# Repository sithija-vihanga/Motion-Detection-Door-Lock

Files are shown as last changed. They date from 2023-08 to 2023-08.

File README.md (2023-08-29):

# Access Smart: Smart Door Lock with Motion Detection

Access Smart is a revolutionary smart door lock that combines motion detection technology and a 4-digit PIN entry system for enhanced security and convenience. This project report provides insights into its specifications, features, assembly instructions, and testing methodologies.

<div align="center">
  <a href="https://github.com/sithija-vihanga/Motion-Detection-Door-Lock/assets/116638289/a954cdd1-04aa-4a93-a124-b1647b821518">
    
  </a>
  <a href="https://github.com/sithija-vihanga/Motion-Detection-Door-Lock/assets/116638289/baeaff62-b7b3-4b20-9fbe-9ba9ac5b796d">
    
  </a>
</div>

## Abstract

Access Smart is a groundbreaking smart door lock that redefines access control for both homes and businesses. This innovative security solution seamlessly integrates motion detection technology and a 4-digit PIN entry system, providing robust security and convenience. With continuous AC power and a reliable Li-ion battery backup, Access Smart operates flawlessly in any situation. The standout feature is its GSM SIM 900A module, allowing real-time SMS alerts for suspicious activities near the door. This report covers specifications, Bill of Materials (BoM), schematics, SolidWorks designs, and more, making Access Smart the ideal solution for modern access control needs.

## Features

- Continuous Power Supply: Utilizes a 12V, 2A power adaptor for uninterrupted operation.
- Backup Power: Employs a TP4056 Li-ion battery charger for backup power.
- Overcharging and Short Circuit Protection: TP4056 module ensures safe charging.
- Buzzer for Notifications: Provides audible alerts for PIN entry or motion detection.
- Manual and Automatic Modes: Secure PIN entry or automatic unlocking via motion detection.
- Easy Manual Unlocking: Pushbutton located inside the house for manual unlocking.
- Intruder Alert: Sends SMS alerts for suspicious activity using PIR sensor and GSM module.

## Specifications

- Microcontroller: Atmega 328p
- Power Supply: 12V, 2A AC Power Adaptor
- Backup Power: 3.7V 18650 Li-ion Battery
- Battery Charger: TP4056 Module with Overcharging and Short Circuit Protection
- User Input: 4x4 Keypad (4-Digit PIN Entry), PIR Sensor (Motion Detection)
- Output: Buzzer, MG90 Metal Servo for Locking Mechanism
- Communication: GSM SIM 900A Module
- Dimensions: 15cm x 12cm

## Installation and Assembly

For detailed assembly instructions and testing procedures, please refer to the [Instructions for Assembly](#instructions-for-assembly) section in the project report PDF.

## Schematics and Designs

<table>
  <tr>
    <td align="center">
      <a href="https://github.com/sithija-vihanga/Motion-Detection-Door-Lock/assets/116638289/c917862b-291f-4ac9-ad59-d2e63189d771">
        Schematics
      </a>
      <br />
      Micro-controller
    </td>
    <td align="center">
      <a href="https://github.com/sithija-vihanga/Motion-Detection-Door-Lock/assets/116638289/85c1b217-390d-44d3-b0bd-173bbbe9d299">
        SolidWorks Design
      </a>
      <br />
      Output-Sensors
    </td>
    <td align="center">
      <a href="https://github.com/sithija-vihanga/Motion-Detection-Door-Lock/assets/116638289/3c5293ef-08f0-4463-aaf7-4a20a470f573">
        
      </a>
      <br />
      Input-Sensors
    </td>
  </tr>
  <tr>
    <td align="center">
      <a href="https://github.com/sithija-vihanga/Motion-Detection-Door-Lock/assets/116638289/dda05f63-1226-4be6-8466-62b0edfdb50d">
        
      </a>
      <br />
      Power-Supply
    </td>
   
  </tr>
 
</table>

## PCB-Design

<div align="center">
  <a href="https://github.com/sithija-vihanga/Motion-Detection-Door-Lock/assets/116638289/617d1b62-6401-47f7-aab8-b14efe2582e4">
    
  </a>
  <a href="https://github.com/sithija-vihanga/Motion-Detection-Door-Lock/assets/116638289/75c37d61-a14a-433e-931d-eac69ed96c83">
    
  </a>
  <a href="https://github.com/sithija-vihanga/Motion-Detection-Door-Lock/assets/116638289/a294f43c-3b7f-41c9-a379-642b3d2e740c">
    
  </a>
</div>

## Solidworks Design

<table>
  <tr>
    <td align="center">
      <a href="https://github.com/sithija-vihanga/Motion-Detection-Door-Lock/assets/116638289/7449ecb6-f5ca-4ba5-8e76-e4704d8df172">
        
      </a>
      <br />
      Image 1
    </td>
    <td align="center">
      <a href="https://github.com/sithija-vihanga/Motion-Detection-Door-Lock/assets/116638289/8038393a-3e27-4574-94a8-9115b9612055">
        
      </a>
      <br />
      Image 2
    </td>
  </tr>
  <tr>
    <td align="center">
      <a href="https://github.com/sithija-vihanga/Motion-Detection-Door-Lock/assets/116638289/9feb5a9c-0473-42e9-8e31-26115e73f358">
        
      </a>
      <br />
      Image 3
    </td>
    <td align="center">
      <a href="https://github.com/sithija-vihanga/Motion-Detection-Door-Lock/assets/116638289/021b66cf-a933-4240-a657-117ee0a4700b">
        
      </a>
      <br />
      Image 4
    </td>
  </tr>
</table>

## Testing and Validation

Refer to the [Testing and validating functionality](#testing-and-validating-functionality) section in the project report PDF for testing procedures.

## License

For more details, please read the complete project report provided in the repository.

---

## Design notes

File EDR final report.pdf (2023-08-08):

### DEPARTMENT OF ELECTRONIC AND TELECOMMUNICATION ENGINEERING UNIVERSITY OF MORATUWA

## EN2160: ELECTRONIC DESIGN REALIZATION

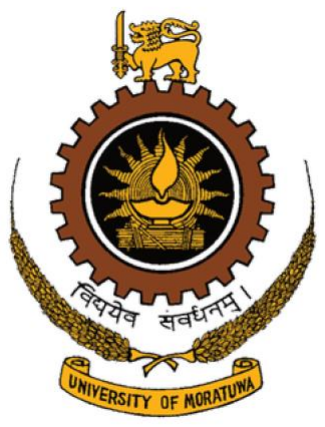
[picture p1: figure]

# Access Smart FINAL PRODUCT REPORT

## Ranaraja S.V

200506K

22

nd July 2023

## Table of Contents

### 1. Introduction

1.1 Overview

### 2. Product Goals

2.1 Functionality
2.2 Market Goals
2.3 Price

### 3. Features

3.1 Uninterrupted power supply
3.2 Charging and discharging protection 3.3 Intruder alerts with SMS

### 4. Specifications

4.1 Motion Detection Technology
4.2 PIN Entry System
4.3 Power Supply: AC Power and Li-ion Battery Backup 4.4 GSM SIM 900A Module for SMS Alerts

### 5. Bill of Materials (BoM)

5.1 Components List and manufacturer

### 6. Schematics and SolidWorks Designs

6.1 Circuit Schematics
6.2 SolidWorks 3D Design
7. Assembly and Testing
7.1 Testing for Power Input and Power LED 7.2 TP4056 Module Charging Test
7.3 Debugging Charging and Discharging Circuit 7.4 ATMEGA and OLED Connection Test
7.5 Motion Sensor Testing
7.6 GSM SIM 900A Module Network Connection Test

## Abstract

Access Smart is a revolutionary smart door lock that redefines door access control for both homes and businesses. This advanced security solution seamlessly integrates motion detection technology and a 4-digit PIN entry system, ensuring enhanced security and convenience. With continuous power supply through AC power and a reliable Li-ion battery backup, Access Smart operates flawlessly in any situation.

The standout feature of Access Smart lies in its incorporation of a GSM SIM 900A module, enabling real-time SMS alerts when suspicious activities are detected near the door. The product report provides comprehensive insights into its specifications, Bill of Materials (BoM), schematics, SolidWorks designs, conceptual design, and preliminary design. Market goals are directed towards homeowners, office spaces, and small businesses seeking an intelligent and modern access control system at a competitive price point. Assembling instructions and testing methodologies are also covered to ensure seamless implementation and optimum functionality. Access Smart, with its cutting-edge technology, convenience, and robust security measures, promises to be the go-to solution for modern door access control needs.

### Smart Door Lock with Motion Detection – Report

### 1. Introduction

Introduction:
The smart door lock with motion detection is designed to provide enhanced security and convenience for door access. It incorporates features intruder alerts using SMS facility to pre-entered phone number, motion detection automatic lock and continuous power supply through AC power and backup power using a Li-ion battery. The lock offers two modes: manual mode with a 4-digit PIN entry and automatic mode utilizing motion detection. This innovative device aims to safeguard premises from potential threats by detecting suspicious activities near the door and sending real-time SMS alerts using the GSM SIM 900A module.

Product Goals:
The primary functionality of the smart door lock is to offer secure and convenient access control to residential and commercial spaces. It combines motion detection and PIN entry to ensure only authorized individuals can enter the premises. The market goals focus on targeting homeowners, office spaces, and small businesses seeking an efficient and modern access control system. The pricing strategy aims to strike a balance between affordability and value, making the smart door lock an attractive choice for consumers seeking advanced security solutions.

Price
Approximate Cost per Unit – Rs. 18,000.00
Market Price – Rs. 20,000.00
Annual Gross Profit – Rs. 200,000.00

### 2. Features

- Continuous Power Supply: Utilizes a 12V, 2A power adaptor to provide uninterrupted power to the smart door lock.
- Backup Power: Employs a TP4056 Li-ion battery charger to charge a 3.7V 18650 battery, offering backup power in case of AC power failure.
- Overcharging and Short Circuit Protection: The TP4056 module ensures safe charging of the Li-ion battery by providing overcharging and short circuit protection.
- Buzzer for Notifications: Incorporates a buzzer to provide audible notifications for various events, such as successful/unsuccessful PIN entry or motion detection.
- Manual Mode: Enables secure access with a 4-digit PIN. The door can be opened by entering the correct PIN.
- Automatic Mode: Utilizes motion detection to automatically unlock the door when motion is detected.
- Easy access for door lock from inside the house: pushbutton is located on the other side of the door lock, allowing for easy manual unlocking from inside.
- Trigger Mechanism: Employs an MG90 metal servo to trigger the locking mechanism securely.
- Intruder alert: Notify users when suspicious activity is detected near the door using PIR sensor readings through SMS facility.

### 3. Specifications

Microcontroller: Atmega 328p
Power Supply: 12V, 2A AC Power Adaptor
Backup Power: 3.7V 18650 Li-ion Battery
Battery Charger: TP4056 Module with Overcharging and Short Circuit Protection User Input: 4x4 keypad (4-Digit PIN Entry), PIR sensor (Motion Detection) Output: Buzzer, MG90 Metal Servo for Locking Mechanism
Communication: GSM sim 900A module
Dimensions: 15cm x 12cm

### 04. Bill of Materials (BoM)

Component | Manufacturer | Shop
Diodes 1N4007 x 10 | Diodes Incorporated | Arrow
Capacitors (electrolytic) | Panasonic | Arrow
1uF x 5 | Panasonic | Arrow
10uF x 5 | Panasonic | Arrow
Capacitors (non-electrolytic) | Vishay | LCSC
22pF x 5 | Vishay | LCSC
Crystal Oscillator 16MHz | Abracon | LCSC
Voltage Regulators | STMicroelectronics | Arrow
L7805CV x 3 | STMicroelectronics | Arrow
L78S05 x 3 | STMicroelectronics | Arrow
SMD Green LED x 5 | Lite-On Technology | Arrow
TP4056 Modules x 2 | | Tronic.lk
12V Power Adaptor | - -
2-pin Power Connectors x 5 | JST | LCSC
3-pin Header Connectors x 5 | JST | LCSC

4-pin Header Connectors x 5 | JST | LCSC
8-pin Connectors x 2 | JST | LCSC
Li-ion Single Battery Case x 2 | Adafruit | LCSC
PIR Motion Sensor x 1 | HC-SR501 | Tronic.lk
Push Button x 1 | Tactile Push Button | Tronic.lk
Buzzer x 1 | Piezo Buzzer | LCSC
1K x 10 | Vishay | LCSC
10K x 10 | Vishay | LCSC
Atmega 328p x 1 | | LCSC
Upconverter (5V - 24V) | - | Tronic.lk
GSM Sim900A module | - | LCSC

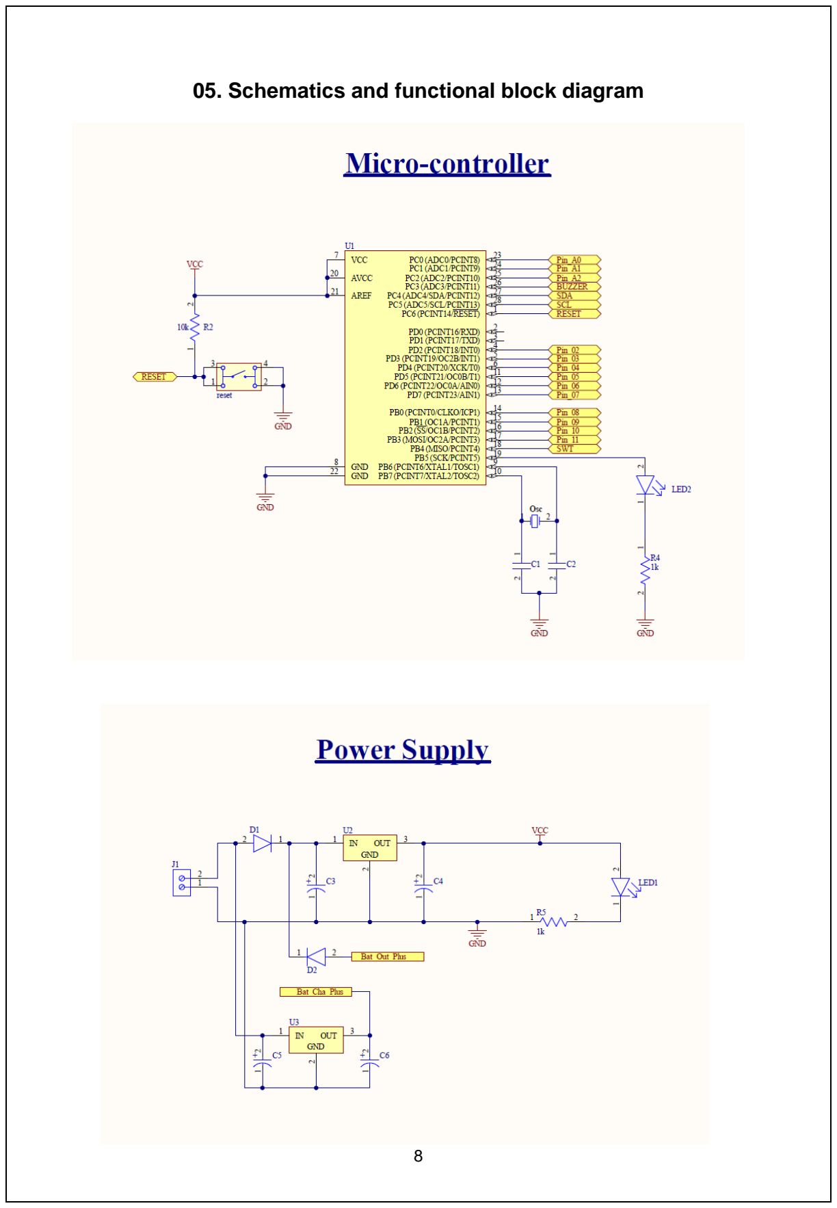
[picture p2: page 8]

### 05. Schematics and functional block diagram

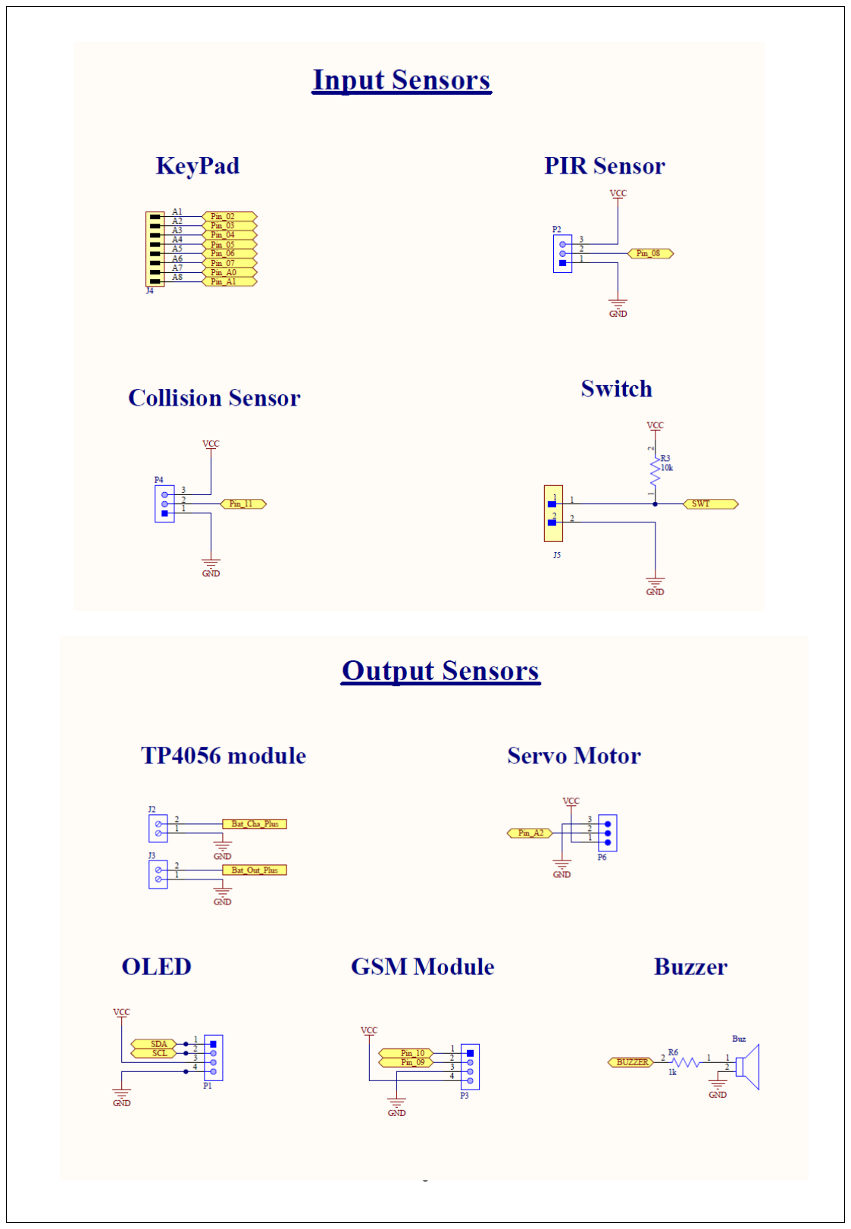
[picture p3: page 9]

### Functional Block diagram

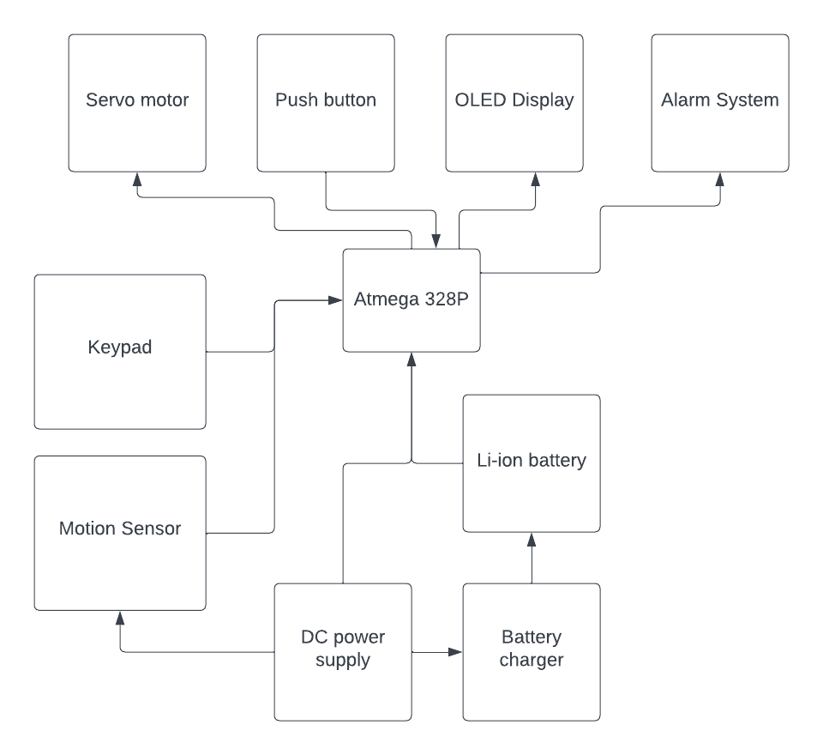
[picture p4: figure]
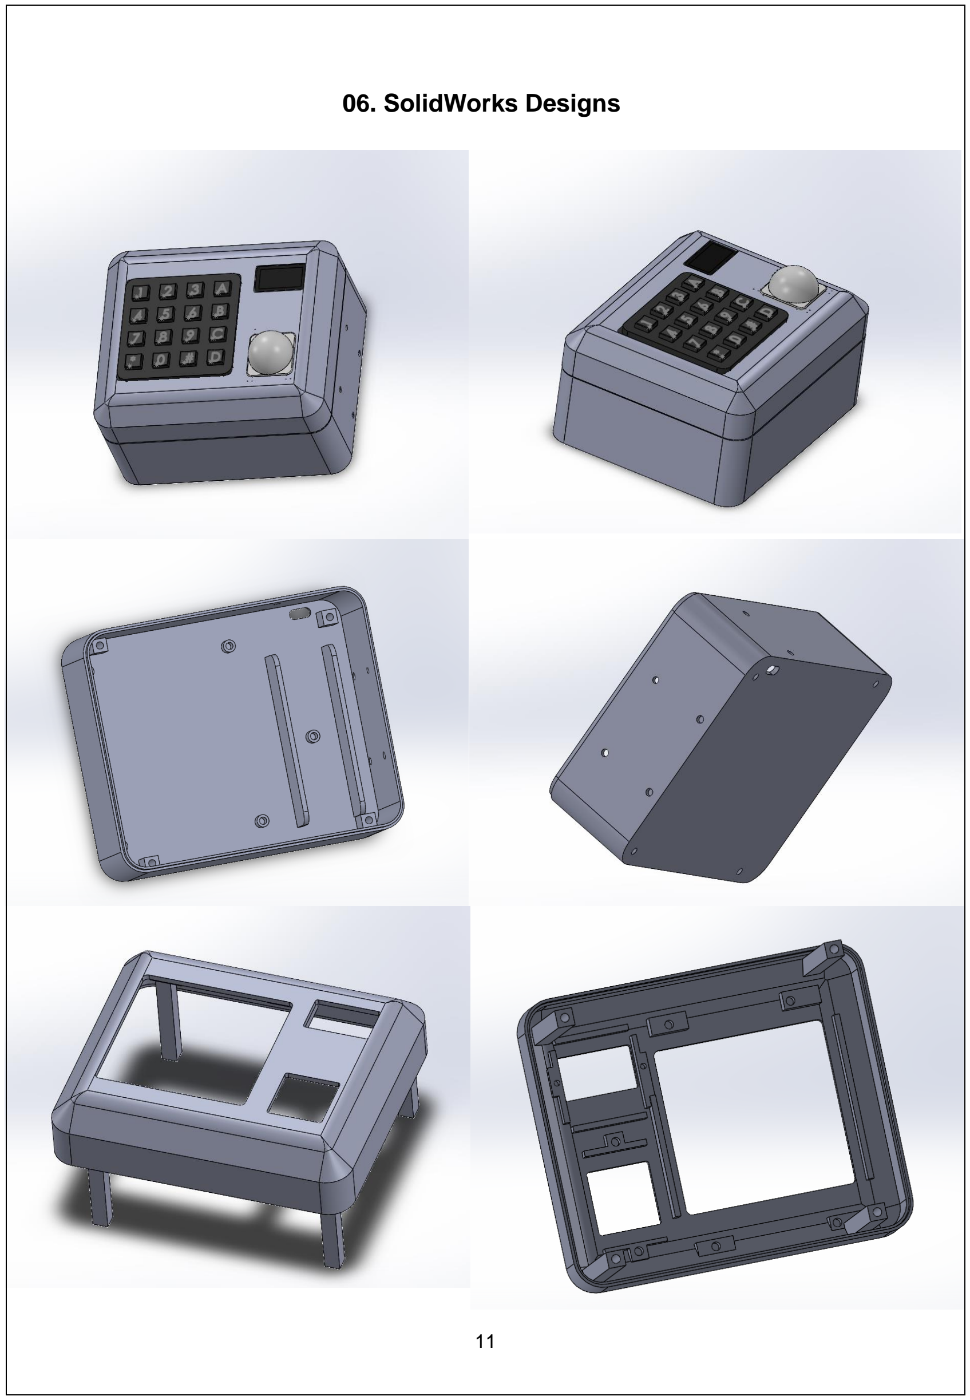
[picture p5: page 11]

### 06. SolidWorks Designs

### 07.Instructions for Assembly

Before proceeding with the assembly of the smart door lock, ensure that you have all the required components and tools ready. Follow these step-by-step instructions to assemble the device:

Step 1: Gather Components and solder the PCB.
- Refer to the Bill of Materials (BoM) and make sure you have all the necessary components at hand.
- Solder the components to the PCB along with the connectors according to the schematic.
Step 2: Prepare the Enclosure
- Assemble and prepare the enclosure for the smart door lock.
- Mount keypad, oled display and PIR sensor to the enclosure lid and fix them with 3mm diameter screws securely within the enclosure.
- Use JST connectors to connect OLED, PIR sensor and keypad to the PCB.
Step 3: Connect the Microcontroller
- Connect the Atmega 328p microcontroller to the appropriate pin headers on the PCB.
- Ensure proper orientation and alignment of the microcontroller.
Step 4: Connect Power Supply and Battery
- Connect the 12V, 2A AC power adapter to the power input of the PCB.
- Attach the TP4056 Li-ion battery charger to the PCB and connect the 3.7V 18650 Li-ion battery to the charger.
- Double-check the polarity and connections to avoid any damage to the components. Connect the Upconverter to the named terminal blocks in the PCB.
- Mount the TP4056 module and Upconverter before mounting PCB to the enclosure.
Step 5: Wiring
- Refer to the schematics to determine the necessary wiring connections between the PCB and the external modules (TP4056 module, Upconverter module, Battery pack).
- Use appropriate wires (JST connectors) and connectors (Terminal blocks) to make secure and reliable connections according to the schematics.
Step 6: Set Up the MG90 Metal Servo
- Attach the MG90 metal servo to the locking mechanism as per the SolidWorks design.
- Ensure smooth movement of the servo's arm to trigger the locking mechanism effectively.
- Then connect the metal bar for door lock to the servo motor using 2.5mm diameter screws.

Step 7: Firmware Upload
- Prepare the firmware (hex file or Arduino code) for the microcontroller with the required code for motion detection, PIN entry, and control logic.
- Upload the firmware to the microcontroller using a suitable programmer or upload the firmware and then insert the microcontroller to the PCB.
Step 8: Test the Components
- Verify that the keypad is functioning correctly for PIN entry.
- Test the motion detection sensor to ensure it accurately detects motion.
- Check the buzzer for proper notifications and feedback.
- Validate the MG90 servo for smooth operation and secure locking.
Step 9: Assemble the Enclosure
- Carefully place the PCB on the mounting holes within the enclosure.
- Secure all components and wiring inside the enclosure to prevent damage during operation.
- Close and fasten the enclosure appropriately, making sure it is well-sealed and fix it with 3mm diameter screws.
Step 10: Final Checks
- Double-check all connections and wiring to avoid any potential short circuits.
- Confirm that the power supply and battery connections are secure.
- Test the device's functionality thoroughly to ensure everything works as expected. If the product is malfunctioning, please refer the next chapter about product testing and verification.
Step 11: Installation
- Install the smart door lock on the intended door, keeping hardware components within the wall to ensure the safety.
- Ensure the lock is properly aligned and secured to prevent any issues with the locking mechanism.

### 08. Testing and validating functionality

### 1. Check Input Power and Power LED:

- Ensure the AC adaptor is connected to the smart door lock.
- Verify if the Power LED on the device is turned on, indicating that it is receiving power from the AC adaptor.

### 2. TP4056 Module Charging:

- Check if the TP4056 charging module is receiving the required voltage from the power source.
- Confirm that the TP4056 module is charging the Li-ion battery as intended.

### 3. Check Voltage Stability of TP4056 Output:

- While the AC adaptor is turned off, observe the voltage on the output terminals of the TP4056 module.
- Ensure that the voltage remains constant, indicating the battery is supplying power to the system without interruption.

### 4. Debug Charging and Discharging Circuit:

- If the voltage on the TP4056 output terminals fluctuates when the AC adaptor is turned off, troubleshoot and debug the charging and discharging circuit based on the schematic provided.

### 5. Connect Atmega and OLED:

- Connect the Atmega chip and OLED display components to the system.
- Ensure that the OLED display turns on, providing visual feedback of the system status.

### 6. Test Motion Sensor:

- Verify the motion sensor's functionality by observing the output displayed on the OLED screen when motion is detected.

### 7. Check GSM SIM 900A Module Connection:

- After powering on the system with the battery, allow up to 3 minutes for the GSM SIM 900A module to connect to the network for communication.
- Check the status of LEDs on the GSM SIM 900A module to confirm network connection.

By following these testing procedures, you can ensure that Access Smart functions correctly and reliably, providing users with the enhanced security and convenience it promises.

## Appendix

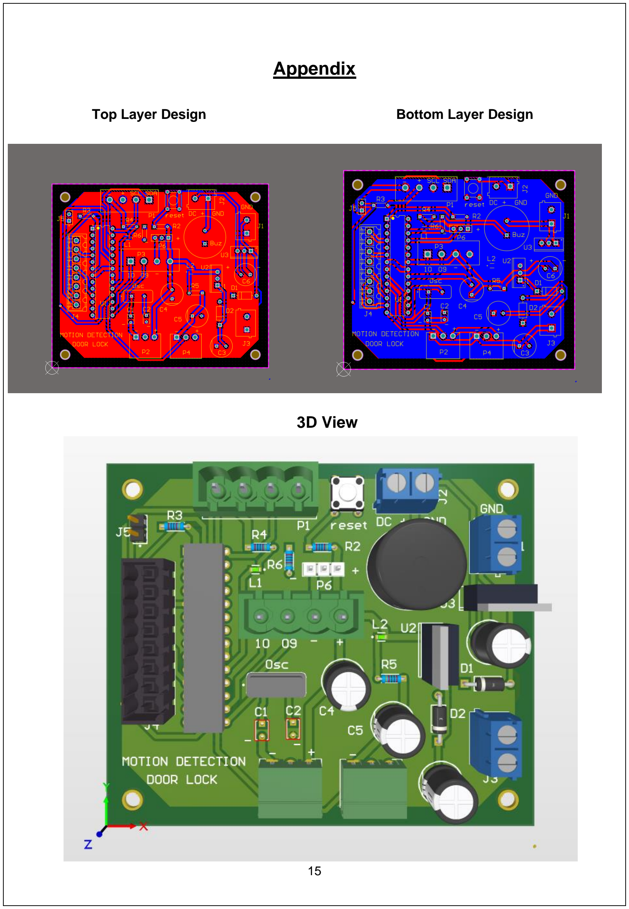
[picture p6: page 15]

Top Layer Design | Bottom Layer Design

### 3D View

## Final Assembly view

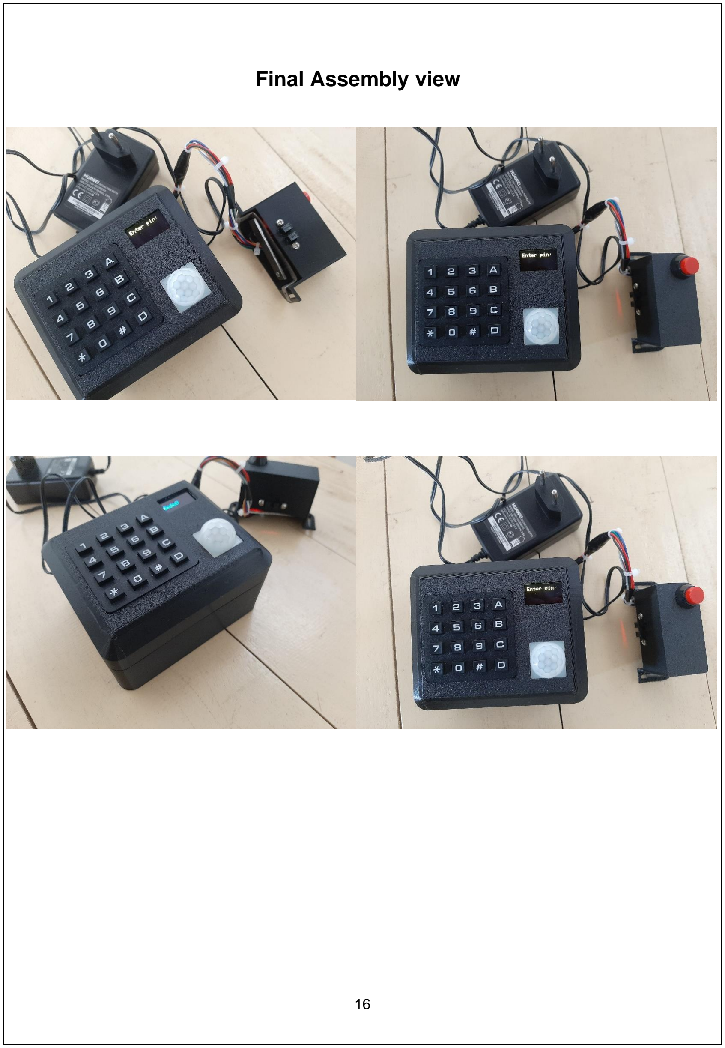
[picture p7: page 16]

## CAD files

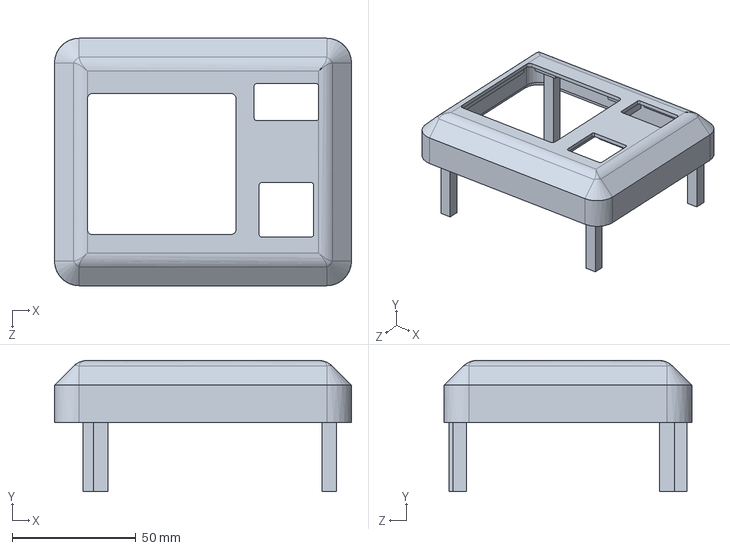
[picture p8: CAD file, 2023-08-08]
Solidoworks-Design/part02.SLDPRT
120.0 x 53.0 x 100.0 mm

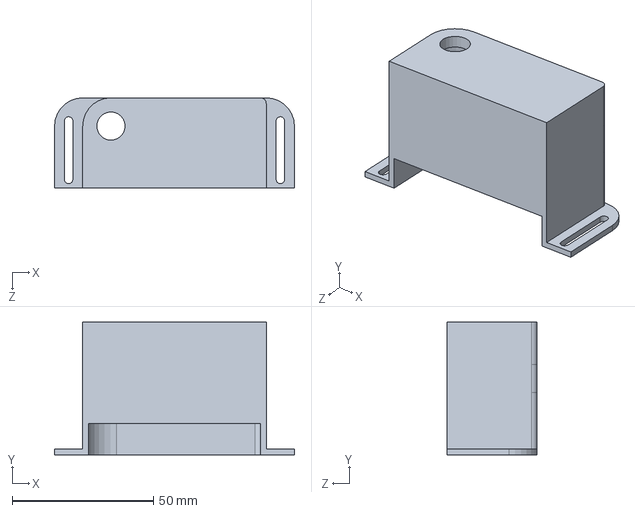
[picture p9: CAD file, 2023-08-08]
Solidoworks-Design/holder.SLDPRT
85.0 x 47.0 x 32.0 mm

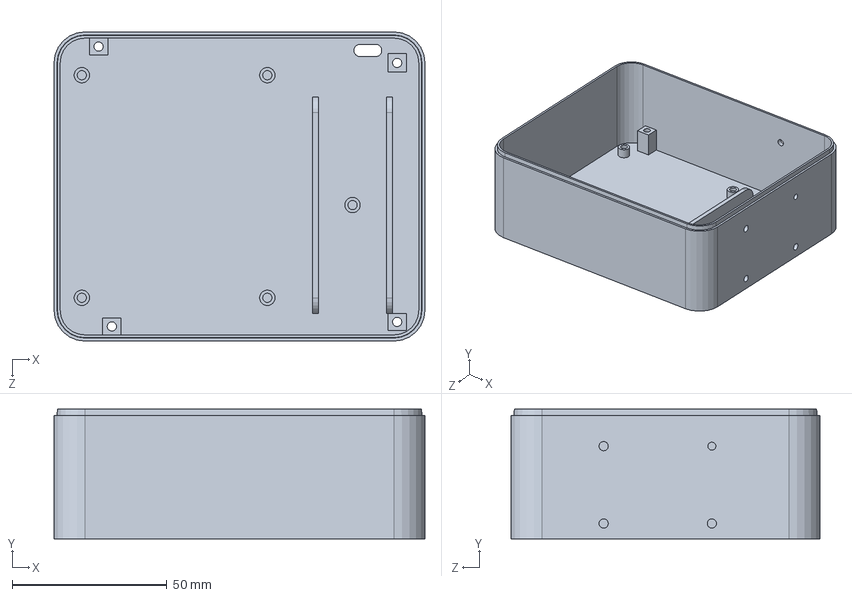
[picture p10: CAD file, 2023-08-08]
Solidoworks-Design/part01.SLDPRT
120.0 x 42.0 x 100.0 mm

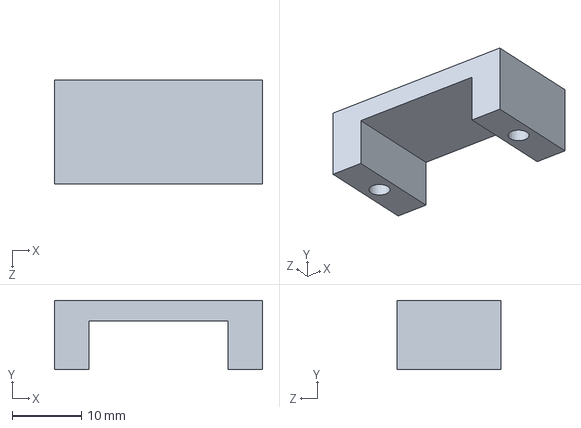
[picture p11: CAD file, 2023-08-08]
Solidoworks-Design/clip.SLDPRT
30.0 x 10.0 x 15.0 mm

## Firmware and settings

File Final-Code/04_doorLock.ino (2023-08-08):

#include <Wire.h>
#include <Keypad.h>

#include <Adafruit_GFX.h>
#include <Adafruit_SSD1306.h>

#define SCREEN_WIDTH 128 // OLED display width,  in pixels
#define SCREEN_HEIGHT 64 // OLED display height, in pixels

int ledPin = 13;                // choose the pin for the LED
int inputPin = 8;               // choose the input pin (for PIR sensor)
int pirState = LOW;             // we start, assuming no motion detected
int val = 0;                    // variable for reading the pin status
 

// declare an SSD1306 display object connected to I2C
Adafruit_SSD1306 oled(SCREEN_WIDTH, SCREEN_HEIGHT, &Wire, -1);

///////////////////////////// For key board ////////////////////////////////////


String password ="7777";

const byte ROWS = 4; /* four rows */
const byte COLS = 4; /* four columns */
/* define the symbols on the buttons of the keypads */
char hexaKeys[ROWS][COLS] = {
  {'1','2','3','A'},
  {'3','4','5','B'},
  {'6','7','8','C'},
  {'*','0','#','D'}
};
byte rowPins[ROWS] = {5,4,3,2}; /* connect to the row pinouts of the keypad */
byte colPins[COLS] = {A1,A0,7,6}; /* connect to the column pinouts of the keypad */

/* initialize an instance of class NewKeypad */
Keypad customKeypad = Keypad( makeKeymap(hexaKeys), rowPins, colPins, ROWS, COLS); 

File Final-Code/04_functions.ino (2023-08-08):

void printToOled(String text, int x, int y){
      oled.clearDisplay(); // clear display
      oled.setTextSize(2);          // text size
      oled.setTextColor(WHITE);     // text color
      oled.setCursor(10, 30);        // position to display
      oled.println(text); // text to display
      oled.display();
}


void checkPassword(){
    String pin = "";
    int cursorX = 10;

    //oled.clearDisplay(); // clear display
    printToOled("Enter pin:",0,40);
    delay(500);
    bool pinProtected = true;
    while(pinProtected){
      char customKey = customKeypad.getKey();
      if (customKey){
        if(cursorX>=58){
          if(pin == password){
            oled.clearDisplay(); // clear display
            printToOled("Access Granted!",0,15);
            delay(500);
            //doorLock(true);
            break;
          }
          else{
            oled.clearDisplay(); // clear display
            printToOled("Access Denied!",0,15);
            delay(500);
            break;
          }
        }
        if(customKey == '#'){
          oled.clearDisplay(); // clear display
          printToOled("Canceled",0,0);
          break;
        }
        else{
        Serial.println(customKey);
        printToOled(String(customKey),cursorX,20);
        pin+=customKey;
        cursorX+=12;
        Serial.println(pin);
        //Serial.println(cursorX);
        }
      }
  }
  

}


void checkIntruders(){
  val = digitalRead(inputPin);  // read input value
  
  if (val == HIGH)  // check if the input is HIGH
  {            
    digitalWrite(ledPin, HIGH);  // turn LED ON
  
    if (pirState == LOW) 
  {
      Serial.println("Motion detected!"); // print on output change
//      oled.clearDisplay(); // clear display
//      oled.setTextSize(2);          // text size
//      oled.setTextColor(WHITE);     // text color
//      oled.setCursor(10, 30);        // position to display
//      oled.println("detected!"); // text to display
//      oled.display();
      printToOled("detected1",0,20);
      delay(100);    
      pirState = HIGH;
    }
  } 
  else 
  {
    digitalWrite(ledPin, LOW); // turn LED OFF
  
    if (pirState == HIGH)
  {
      Serial.println("Motion ended!");  // print on output change
//      oled.clearDisplay(); // clear display
//      oled.setTextSize(2);          // text size
//      oled.setTextColor(WHITE);     // text color
//      oled.setCursor(10, 30);        // position to display
//      oled.println("ended!"); // text to display
//      oled.display();
       printToOled("ended2!",0,20);
      delay(100);    
      pirState = LOW;
    }
  }

  }

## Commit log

2023-04-15 pcb layout
    [doorLock_schematic.SchDoc, door_lock_pcb.PcbDoc, motion_detection_door_lock.PrjPcb]
2023-04-17 Solidworks assembly file v01
